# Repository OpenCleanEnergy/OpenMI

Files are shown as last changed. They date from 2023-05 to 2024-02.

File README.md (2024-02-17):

# OpenMI

View Schematics and PCB Layout on 

## What is our goal?

We want to build an open source micro-inverter.

## Why making this open source?

1. **Transparency and Trust:** Open sourcing fosters transparency, providing users and developers with complete visibility into how the microinverter works. This builds trust within the community and ensures that the technology operates as advertised.

2. **Collaborative Development:** The open-source model encourages collaboration from a diverse group of developers, engineers, and enthusiasts. This collective effort often leads to innovative solutions, enhanced functionality, and improved performance.

3. **Rapid Iteration and Improvement:** With a broader community involved, improvements and bug fixes can happen at a faster pace. Developers can quickly identify and rectify issues, leading to a more robust and reliable microinverter.

4. **Customization and Adaptability:** Open sourcing allows users to modify the microinverter to suit their specific needs. Whether it's adapting the hardware for different solar panel configurations or modifying the software for specific energy management, users have the freedom to customize.

5. **Cost-Effectiveness and Affordability:** By making the designs and software open source, the overall cost of development can be reduced. Individuals and organizations can access the project without expensive licensing fees, making renewable energy solutions more accessible to a wider audience.

6. **Knowledge Sharing and Learning Opportunities:** Open-source projects serve as valuable learning resources for students, researchers, and professionals looking to understand the technology, its design principles, and best practices in renewable energy.

7. **Global Impact and Adoption:** Open sourcing allows for widespread adoption and deployment, especially in regions where cost and accessibility are significant factors. It facilitates the dissemination of renewable energy technology to areas that need it most.

8. **Alignment with Ethical and Environmental Values:** Open-source projects align with values of openness, collaboration, and sustainability. By promoting transparency and knowledge sharing, it contributes to a sustainable and ethical approach to technology development and use.

9. **Long-Term Sustainability and Maintenance:** With a diverse community contributing to the project, the microinverter is likely to remain relevant and actively maintained over the long term, ensuring its sustainability and continued development.

## What specifications should the micro-inverter have?

Comparison of micro-inverters with rated output power between 350VA and 400VA:

| Model | HM-350[^HM] | HM-400[^HM] | IQ7A[^IQ7A] |EVT300[^EVT300]|TSOL-M800[^TSOL] |
|:---|:---:|:---:|:---:|:---:|:---:|
| Manufacturer | Hoymiles | Hoymiles | Enphase | Envertech | TSUN |
| Number of solar panels | 1 | 1 | 1 | 1 | 2 |
| Recommended input power (W) | 280-470+ | 320-540+ | 295-460 | 180-420+ |2 $\cdot$ 280-440|
| $V_{MPPT,min}$ (V) | 33 | 34 | 38 (18) | 24 | 33 |
| $V_{MPPT,max}$ (V) | 48 | 48 | 43 (58) | 45 | 48 |
| Start-up voltage (V) | 22 | 22 | 22 | - | - |
| Operating volage range (V) | 16-60 | 16-60 | 16-58 | 18-54 | 16-60 |
| Maximum input current (A) | 11.5 | 12 | 12 | 12 | 11.5 |
| Maximum input short circuit current (A)| 15 | 15 | 20 | 15 | 15 |
| Rated output power (VA) | 350 | 400 | 349 | 300 | 600 |
| Peak efficiency (%) | 96.7 | 96.7 | 97.7 | 95.4 | 96.7 |
| CEC weighted efficiency (%) | 96.5 | 96.5 | 97.0 | 95.0 | 96.5 |

Subject to further modifications, the micro-inverter should have the following specifications:
- Efficiency > 90%
- Operating range: 16V - 58V
- Input power from solar panel: 350W - 550W
- Power: 400VA with possibility of software limitation.
- Power factor ≈ 1
- Total Harmonic Distortion (THD) < 5%.
- Electrical isolation between solar module and grid voltage
- Temperature range: -40 °C to 60 °C
- Interfaces:
  - WIFI with [SunSpec Modbus](https://sunspec.org/sunspec-modbus-specifications/)
  - Powerline Communication (PLC)

Optional features:
- Adjustable Power Factor

#### PV panel specifications

The following table shows a comparison of different solar modules and their technical data, which were adopted as a guide for designing the microinverter.

| Model | WS350M[^WS350M]| Meyer Burger White[^MB]| JAM72S-30-550-MR[^JA] |
|:---|:---:|:---:|:---:|
| Manufacturer | Wattstunde | Meyer Burger White | JA Solar |
| Power (Wp) | 350 | 400 | 550 |
| Short Circuit Current (A) | 9.68 | 10.9 | 14.00 |
| Open Circuit Voltage (V) | 46.7 | 44.6 | 49.9 |
| $V_{MPPT}$ (V) | 38.1 | 38.6 | 41.96 |
| $I_{MPPT}$ (A) | 9.19 | 10.4 | 13.11 |

## How will the micro-inverter be technically implemented?

The technical implementation of the micro-inverter will be continuously revised and iteratively improved during the course of the project. Comments and suggestions for improvement are welcome here!

### Topology

During basic research, we first came across the application note [^AN4070]. The design is based on 2 power stages, namely an interleaved isolated DC-DC boost converter and a DC-AC converter. The application note provides a detailed description of the operation and component selection. We apoted and extended several things from the design, especially the DC-AC converter. It is worth mentioning that the capacity of the DC bus is of such low capacitance that it can be implemented as film capacitors, which avoids the eventual lifetime issues with electrolytic capacitors.

For the DC-DC converter we used the application note [^AN2012-09] as guide to integrate a LLC resonant converter into our design. The application note describes the implementation of a 250W grid-connected LLC converter micro-inverter. The design of the resonant corverter consinsts of a *switchwing bridge*, a *LLC tank*, a *transformer* and a *rectifier*.

## How can the micro inverter be simulated?

The circuit design of the micro inverter was simulated in [LTspice](https://www.analog.com/en/design-center/design-tools-and-calculators/ltspice-simulator.html). All LTspice simulations are stored in the [simulation](simulation) folder.
Since the entire circuit design is quickly complex and time-consuming to simulate, the individual building blocks of the circuit were first built and simulated individually. Please mind, that in the current state of the project there are a bunch of LTspice simulations since we discussed a lot of topologies.

The design process of the LLC resonant converter is documented in a [interactive jupyter notebook](simulation/llc-transformer/llc_transformer_design.ipynb).

## Contributing

See [CONTRIBUTING](CONTRIBUTING.md).

## Footnotes

[^HM]: [HM Microinverter Datasheet](https://www.hoymiles.com/wp-content/uploads/downloadupload/Datasheet_HM-300-350-400_AP_EN_V202206.pdf)

[^IQ7A]: [IQ7A Microinverter Datasheet](https://enphase.com/download/iq7a-microinverter-data-sheet)

[^EVT300]: [EVT300 Microinverter Datasheet](https://envertec.com/wp-content/uploads/2022/11/EVT300_Datasheet.pdf)

[^TSOL]: [TSOL-M800 Microinverter Datasheet](https://www.ecoheroes.shop/media/pdf/c9/f6/5b/Datenblatt_Mikrowechselrichter_TSUN_M800_EN.pdf)

[^AN4070]: [AN4070 250 W grid connected microinverter](https://www.st.com/resource/en/application_note/dm00050692-250-w-grid-connected-microinverter-stmicroelectronics.pdf)

[^AN2012-09]: [Resonant LLC Converter: Operation and Design](https://www.infineon.com/dgdl/Application_Note_Resonant+LLC+Converter+Operation+and+Design_Infineon.pdf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)

[^WS350M]: [Wattstunde solar panel 350Wp](https://solarkontor.de/mediafiles/PDF/Solarmodule/Wattstunde/M-Reihe/Datenblatt%20M%20%20v0123.pdf)

[^MB]: [Meyer Burger White solar panel 400Wp](https://www.meyerburger.com/fileadmin/user_upload/PDFs/Produktdatenblaetter/DE/DS_Meyer_Burger_White_de.pdf)

[^JA]: [JA Solar solar panel 550Wp](https://www.jasolar.com/uploadfile/2022/1122/20221122050252648.pdf)

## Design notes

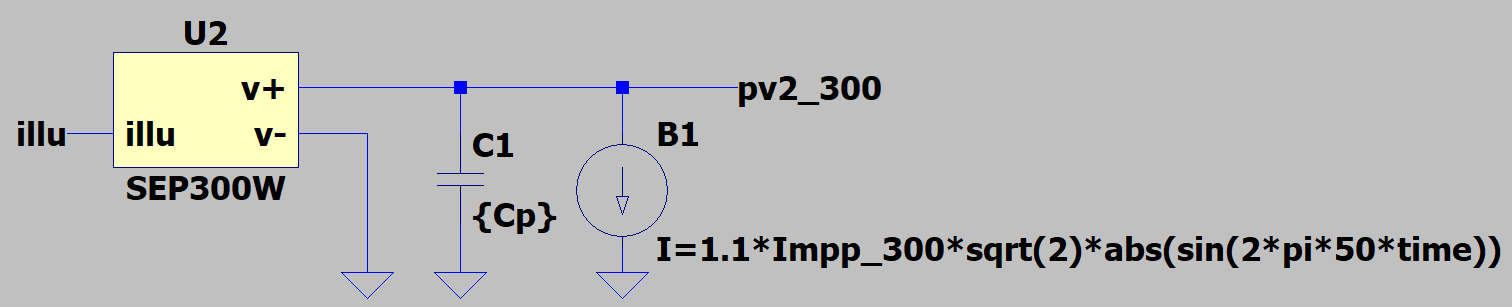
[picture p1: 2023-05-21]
simulation/pv-panel-input/pv-panel-grid-current-source-schematic.png

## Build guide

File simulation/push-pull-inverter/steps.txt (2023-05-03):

0 0
+2.5u 0
+0.005u 0.0015708
+4.995u 0.0015708
+0.005u 0.00314159
+4.995u 0.00314159
+0.005u 0.00471237
+4.995u 0.00471237
+0.005u 0.00628314
+4.995u 0.00628314
+0.005u 0.0078539
+4.995u 0.0078539
+0.005u 0.00942464
+4.995u 0.00942464
+0.005u 0.0109954
+4.995u 0.0109954
+0.005u 0.012566
+4.995u 0.012566
+0.005u 0.0141367
+4.995u 0.0141367
+0.005u 0.0157073
+4.995u 0.0157073
+0.005u 0.0172779
+4.995u 0.0172779
+0.005u 0.0188484
+4.995u 0.0188484
+0.005u 0.0204189
+4.995u 0.0204189
+0.005u 0.0219894
+4.995u 0.0219894
+0.005u 0.0235598
+4.995u 0.0235598
+0.005u 0.0251301
+4.995u 0.0251301
+0.005u 0.0267004
+4.995u 0.0267004
+0.005u 0.0282706
+4.995u 0.0282706
+0.005u 0.0298407
+4.995u 0.0298407
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

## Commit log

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2023-05-15 Fixing values for input capacitance Cp
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2023-05-31 docs: add reference to current-fed power processing docs: fix reference numbers
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2023-06-04 First draft for full bridge dc-dc converter - correct values for output filter are missing
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2023-06-07 docs: add dc-ac-inverter simulation with fixed duty cycle and "random" output filter
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2023-06-13 Initial commit for KiCad project
    [OpenMI.kicad_pcb, OpenMI.kicad_sch]
2023-06-13 Fixing KiCad .gitignore
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2023-06-15 hw: Add draft of ac-dc-inverter
    [OpenMI.kicad_sch]
2023-06-15 hw: Add some possible inductors
    [OpenMI.kicad_sch]
2023-06-16 hw: fix switching frequency -> update required filter inductance
    [OpenMI.kicad_sch]
2023-06-18 hw: Add dc bus power decoupling capacitors
    [OpenMI.kicad_sch]
2023-06-19 hw: Update symbols from library
    [OpenMI.kicad_sch]
2023-06-20 hw: Adding project specific library path for OpenCE symbols
    [OpenMI.kicad_sch]
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2023-06-21 hw: add sheets to separate concerns
    [DC-AC.kicad_sch, DC-DC.kicad_sch, OpenMI.kicad_sch]
2023-06-21 feat(hw): Add slow leg of DC-AC inverter
    [DC-AC.kicad_sch, OpenMI.kicad_sch]
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2023-06-22 fix(hw): connect high-side supply reference with half-bridge output
    [DC-AC.kicad_sch]
2023-06-22 feat(hw): Remove unnecessary pull down restistors docs(hw): Add TODOS for power decoupling
    [DC-AC.kicad_sch]
2023-06-26 feat(hw): Add thoughts for design of input capacitance and inductance
    [DC-DC.kicad_sch]
2023-06-27 feat(hw): Add over temperature output
    [DC-AC.kicad_sch, DC-DC.kicad_sch, OpenMI.kicad_sch]
2023-06-28 docs(hw): Add references for formulas
    [DC-AC.kicad_sch]
2023-06-28 feat(hw): Add DC bus voltage sensing
    [DC-AC.kicad_sch]
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2023-06-30 docs(hw): adds calculation of voltage divider cutoff frequency
    [DC-AC.kicad_sch]
2023-06-30 docs(hw): Adds parameter and results of Coilcraft Power Inductor Finder
    [DC-AC.kicad_sch]
2023-07-02 docs(hw): update DC Bus power decoupling to dos
    [DC-AC.kicad_sch]
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2023-07-05 feat(hw): Adds new "Grid" sheet. Adds grid voltage sense
    [Grid.kicad_sch, OpenMI.kicad_sch]
2023-07-05 fix(hw): Fix hierarchical label direction
    [DC-AC.kicad_sch, OpenMI.kicad_sch]
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2023-07-08 fix(hw): remove OpenCE symbols from sym_lib_table because symbols built by KiCadDbLib are imported from the output directory
2023-07-09 feat(hw): add input inductance and calculations for it
    [DC-DC.kicad_sch]
2023-07-09 feat(hw): add GaN FET GAN7R0-150LBEZ and first considerations for gate driver
    [DC-DC.kicad_sch]
2023-07-09 docs(hw): add more considerations about rise and fall time of GaN FET
    [DC-DC.kicad_sch]
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2023-07-22 feat(hw): adds gate driver `1EDN7550B` with gate resistor values to be discussed
    [DC-DC.kicad_sch]
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2023-07-23 docs(hw): minor fix for GaN FET considerations
    [DC-DC.kicad_sch]
2023-07-23 fix(hw): update labels for GaNs of dc-dc converter
    [DC-DC.kicad_sch, OpenMI.kicad_sch]
2023-07-23 refactor(sim): adds fixed values for sink and source gate resistors for interleaved boost converter
2023-07-23 docs(hw): adds simulation results for charge and discharge time of GaN gate
    [DC-DC.kicad_sch]
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2023-07-31 feat(hw): adds resistors and capacitors from DbLib to GaN FET driver
    [DC-DC.kicad_sch]
2023-07-31 docs(hw): adds link for source of gate resistor recommendations
    [DC-DC.kicad_sch]
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2023-08-06 docs(hw): fixing calculation intermediate step for power consumption of GaN FET gate
    [DC-DC.kicad_sch]
2023-08-06 fix(hw): change GaN FET protection from `SMBJ120A` to `SMBJ100A`
    [DC-DC.kicad_sch]
2023-08-17 docs: Adds to-do to remember high current, high frequency inductors
    [DC-DC.kicad_sch]
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2023-08-29 docs: reworks considerations for transformer turn ratio
    [DC-DC.kicad_sch]
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2023-09-03 docs(hw): adds todo to consider skin effect for current limit of inductor
    [DC-DC.kicad_sch]
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2023-09-05 feat: Adds grid-side filter inductance feat: Replaces outdated filter with placeholder capacitor and damping resistor feat: Adds resistors to gates of slow switching MOSFET to prevent accidental swit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
    [DC-AC.kicad_sch]
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2023-09-13 fix(hw): changes direction of TVS diodes for GaN FET
    [DC-DC.kicad_sch]
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2023-09-13 feat(hw): adds safety resistors to gate of GaN FET
    [DC-DC.kicad_sch]
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2023-09-24 chore(sim): modified interleaved-boost converter sim to show problem of oscillation on the input voltage
2023-09-24 docs(hw): adds todo on where to place transformer in schematic
    [DC-DC.kicad_sch]
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2023-09-26 feat(hw): adds `IDL04G65C` diodes and capacitor to rectifier
    [DC-DC.kicad_sch]
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2023-10-02 feat(hw): Adds RC-Filter with `1206` footprint to MASTERGAN. Values are TBD.
    [DC-AC.kicad_sch]
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2023-10-22 feat(hw): Moves DC-bus sense to Sensing sheet. Adds op-amp for impedance decoupling.
    [DC-AC.kicad_sch, OpenMI.kicad_sch, Sensing.kicad_sch]
2023-10-24 feat(hw): exchanges input inductor and adds first thoughts for dc-dc converter on dc-dc stage
    [DC-DC.kicad_sch]
2023-10-25 refactor(hw): Replaces OPA171 with pin compatible MCP6001T
    [Sensing.kicad_sch]
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2023-10-29 feat(hw): Adds grid-connected EMI filter, adds power relay
    [Grid.kicad_sch]
2023-10-30 feat(hw): adds `LM5163` buck converter but still WIP
    [DC-DC.kicad_sch]
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2023-10-31 refactor(hw): Moves grid voltage sensing to `Sensing`. Refactors labels.
    [DC-AC.kicad_sch, Grid.kicad_sch, OpenMI.kicad_sch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]
2023-10-31 refactor(hw): Adds final safety capacitors to line filter
    [Grid.kicad_sch]
2023-10-31 refactor(hw): reorganizes dc-dc converter sheet for better overview
    [DC-DC.kicad_sch, Input-Capacity.kicad_sch]
2023-11-09 feat: Replaces SPST relay with DPDT relay to disconnect "neutral" as well.
    docs: Add references to international standards for grid connected devices.
    [Grid.kicad_sch]
2023-11-12 feat: Adds grid current sensing using a hall effect sensor.
    [Grid.kicad_sch, OpenMI.kicad_sch, Sensing.kicad_sch]
2023-11-13 feat(hw): Adds grid current alert output to `Sensing`.
    [OpenMI.kicad_sch, Sensing.kicad_sch]
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2023-11-16 feat: finished 5V buck converter for dc-dc stage
    [Buck-Converter.kicad_sch, DC-DC.kicad_sch]
2023-11-18 refactor(hw): uses new symbol for `LM5163` buck converter
    [Buck-Converter.kicad_sch, DC-DC.kicad_sch]
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2023-12-27 feat(hw): Adds `EN` input to enable or disable DC-AC stage.
    [DC-AC.kicad_sch, OpenMI.kicad_sch]
2023-12-27 docs(hw): Adds explanation of why Y2 capacitors do not need overvoltage protection.
    [Grid.kicad_sch]
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2024-01-14 feat(hw): Adds PV module voltage and current sensing (#3)
    * Adds first draft of pv-panel voltage and current sensing.
    * Adds specific values for sense resistors.
    * Set anti-aliasing cutoff frequency to 4.8kHz.
    Adds documentation.
    * Adds ADE7912
    * Tidy up schematics. Adds sheet symbols to root.
    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
    [OpenMI.kicad_sch, PV-Sensing.kicad_sch, Sensing.kicad_sch]
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2024-02-10 docs(hw): adds some considerations about LLC transformer design
    [DC-DC.kicad_sch]
2024-02-10 chore: removes old input chokes and adds hint for current llc design process
    [DC-DC.kicad_sch]
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2024-05-09 fix: workflow by updating image to `kicad8_auto_full:latest`
2024-05-09 docs: fixes link to the llc transformer jupyter notebook
    [DC-DC.kicad_sch]
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2024-05-11 feat: very first draft of adding LLC resonant converter
    [DC-DC.kicad_sch]
